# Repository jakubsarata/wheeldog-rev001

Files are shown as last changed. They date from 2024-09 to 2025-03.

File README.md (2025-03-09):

# Structurally Configurable Mobile Robot - Wheeldog_rev001
<p align="center">
  <table>
    <tr>
      <td></td>
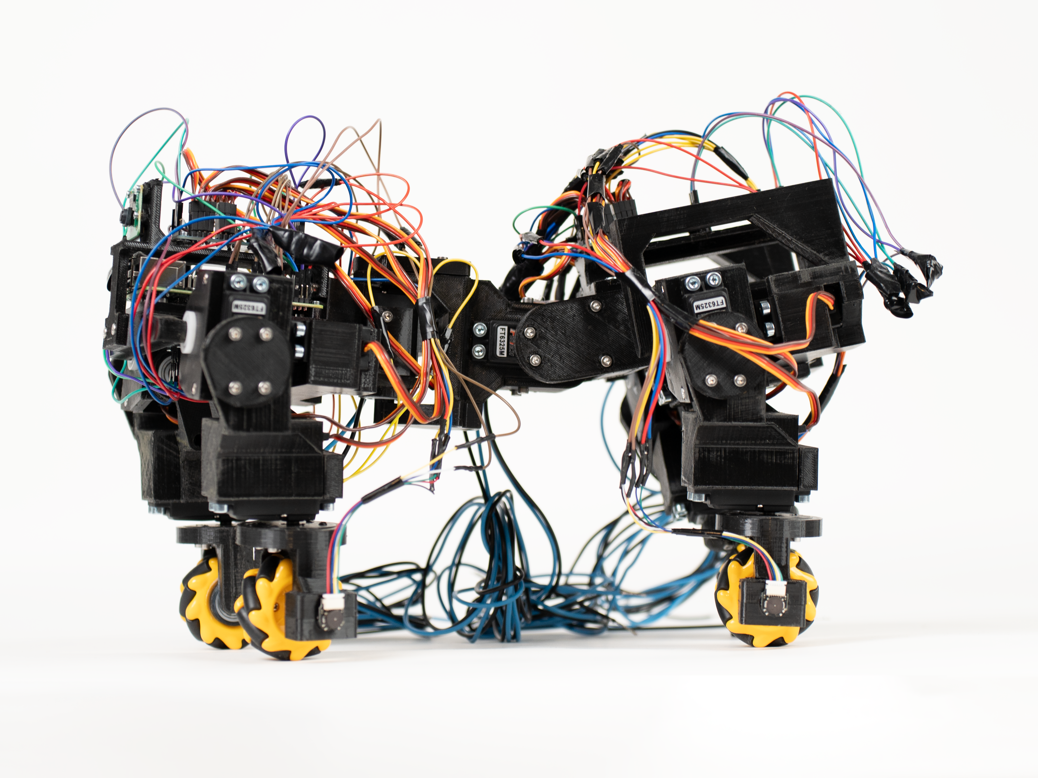
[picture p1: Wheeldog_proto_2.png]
      <td></td>
    </tr>
  </table>
</p>

## Overview
This project presents an open-source **structurally configurable mobile robot**, which combines the benefits of wheeled and legged locomotion. The robot is inspired by designs such as ANYmal, but with enhanced flexibility and mobility due to additional degrees of freedom and omnidirectional wheels.

Originally developed as part of a master's thesis at the **AGH University of Science and Technology**, this project is now available to the open-source community for further development and application.

## Features
- **Hybrid Locomotion**: Utilizes both wheels for speed and efficiency on smooth surfaces, and legs for traversing rough terrains and obstacles.
- **Adaptive Configuration**: The body features three degrees of freedom, allowing for movement akin to natural creatures like lizards.
- **Omnidirectional Wheels**: Enables maneuverability in tight spaces and precise movement control.
- **Simulation and Real-World Testing**: Verified through MATLAB simulations and physical prototyping.
- **Simulink Model**: A simulation model of the platform is available in MATLAB/Simulink R2022b using the Simscape Multibody toolbox.
- **Expandable and Modular**: Designed with 3D printing and modular assembly in mind, allowing for modifications and improvements.

## System Components
### Hardware
- **Actuators**: 15 Feetech FT6325M servomotors
- **Motors**: 4 Pololu 2373 DC motors
- **Main Controller**: Raspberry Pi 4B
- **Motor Drivers**: PCA9685 for servos, M2T256 for DC motors
- **Sensors**:
  - Adafruit 4754 IMU for motion tracking
  - Pololu 4761 encoders for wheel speed measurement
  - Raspberry Pi Camera HD v2 for future vision applications
- **Power Supply**: Laboratory power supply (for prototyping phase)
- **Chassis**: 3D-printed components

### Software
- **Programming Language**: Python & C++
- **Communication Protocols**: I2C for sensor and actuator control

## Getting Started
### Hardware Setup
1. **Assemble the chassis**: 3D print and attach all components as per the provided CAD files.
2. **Connect actuators and sensors**: Follow the wiring diagram.
3. **Power the system**: Use a stable power source for testing.

### Software Setup
To start using the robot, follow the steps outlined in the master’s thesis and the official guides provided by the manufacturers of the respective controllers and sensors. These documents include detailed instructions on setup, wiring, and configuration.

## Contribution
Contributions are welcome, but to ensure proper coordination, all changes must be reviewed before being merged. If you wish to improve or extend functionality:
1.**Fork the repository**
2.**Implement changes or bug fixes**
3.**Submit a pull request for review**

For major changes, please open an issue first to discuss your ideas. No changes will be merged without prior review and approval.

## License
This project is licensed under the **MIT License**, allowing for open collaboration and modifications.

## Acknowledgments
This project was initially developed as a **Master’s Thesis** at AGH University of Science and Technology.

## Contact
For inquiries, contributions, or discussions, feel free to reach out via GitHub Issues or email at **jakub.sarata@gmail.com**.

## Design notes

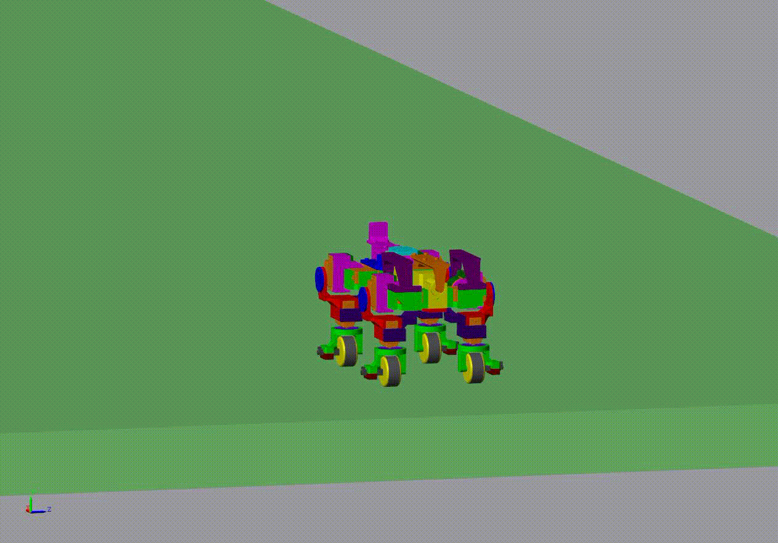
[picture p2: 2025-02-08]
Records/Crab_gait.gif

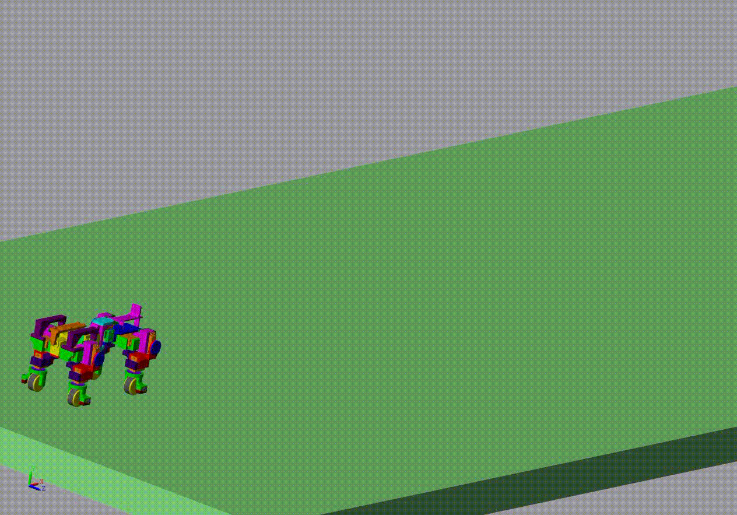
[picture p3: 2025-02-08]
Records/Crawling.gif

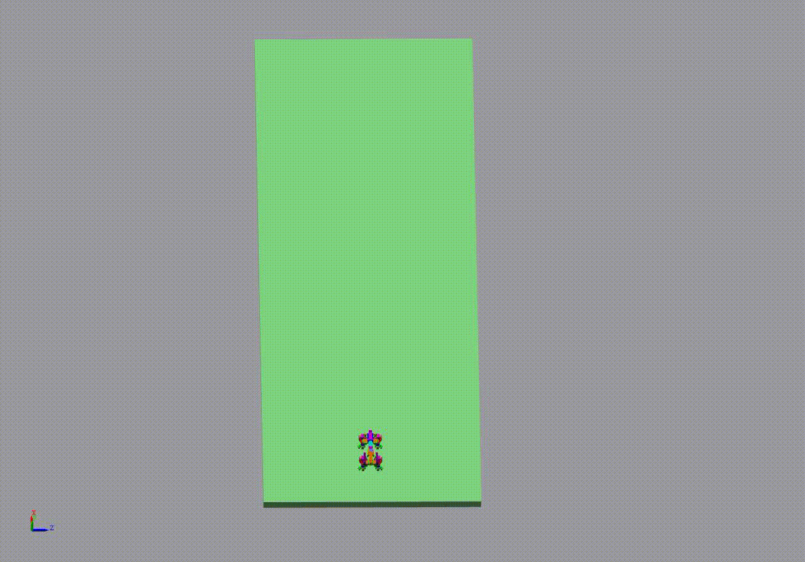
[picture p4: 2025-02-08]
Records/Slalom.gif

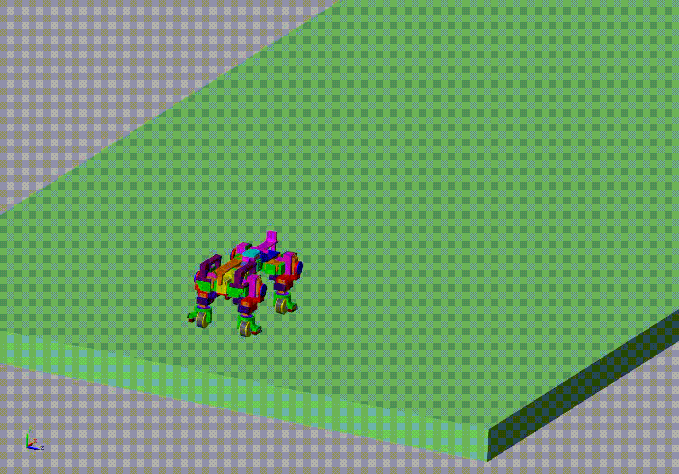
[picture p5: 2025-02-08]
Records/Lizard_gait.gif

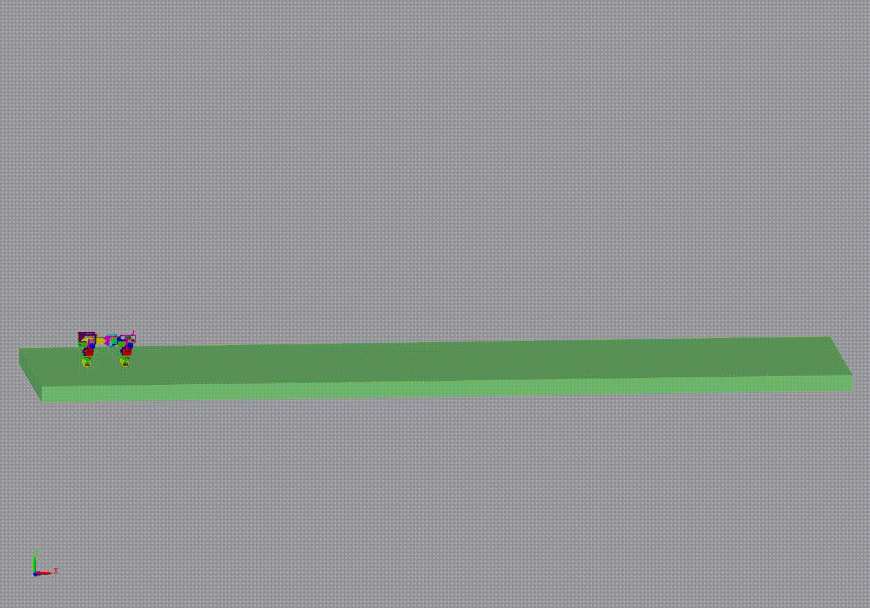
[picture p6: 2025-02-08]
Records/Driving_with_active_suspension.gif

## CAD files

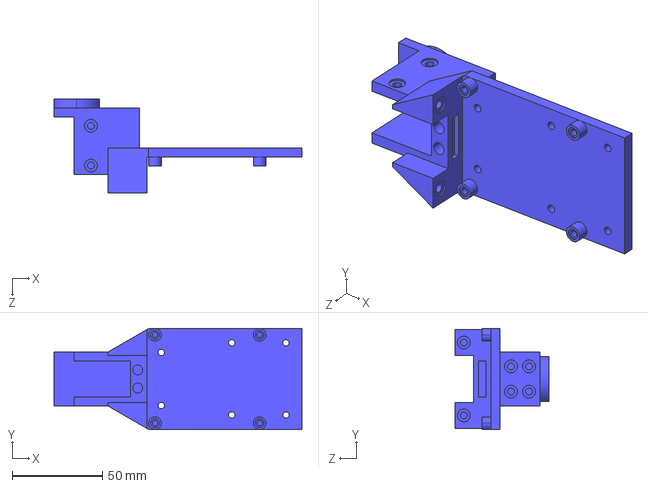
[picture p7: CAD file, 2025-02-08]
Project/Base/009_001_Underside_front.STEP
137.5 x 56.0 x 52.3 mm

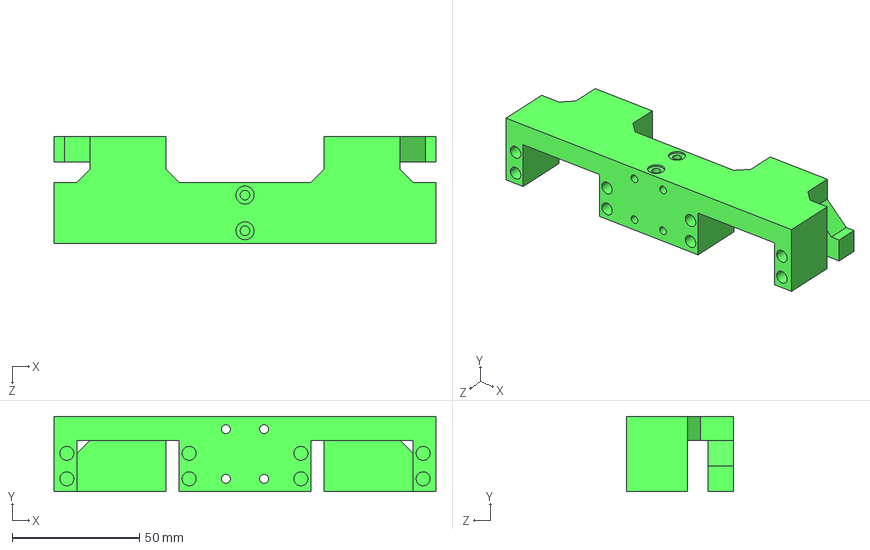
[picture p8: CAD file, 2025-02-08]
Project/Leg/010_017_Left_right_servo_mount_back.STEP
150.0 x 29.5 x 42.0 mm

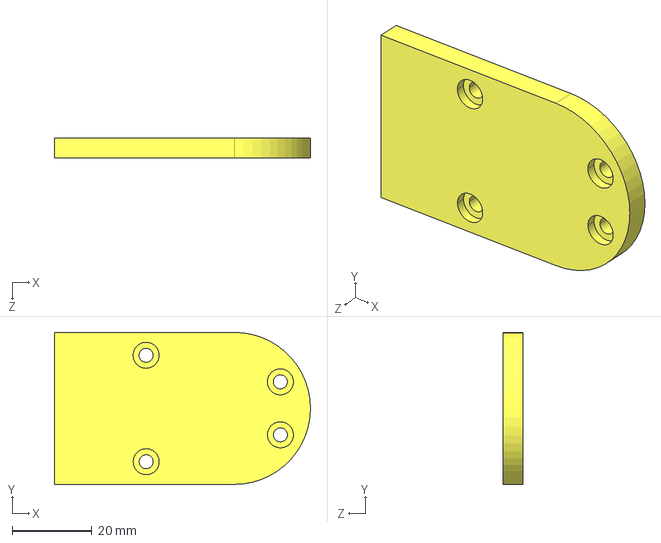
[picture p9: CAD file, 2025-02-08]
Project/Base/009_006_Up_down_connector_lock.STEP
64.0 x 38.0 x 5.00 mm

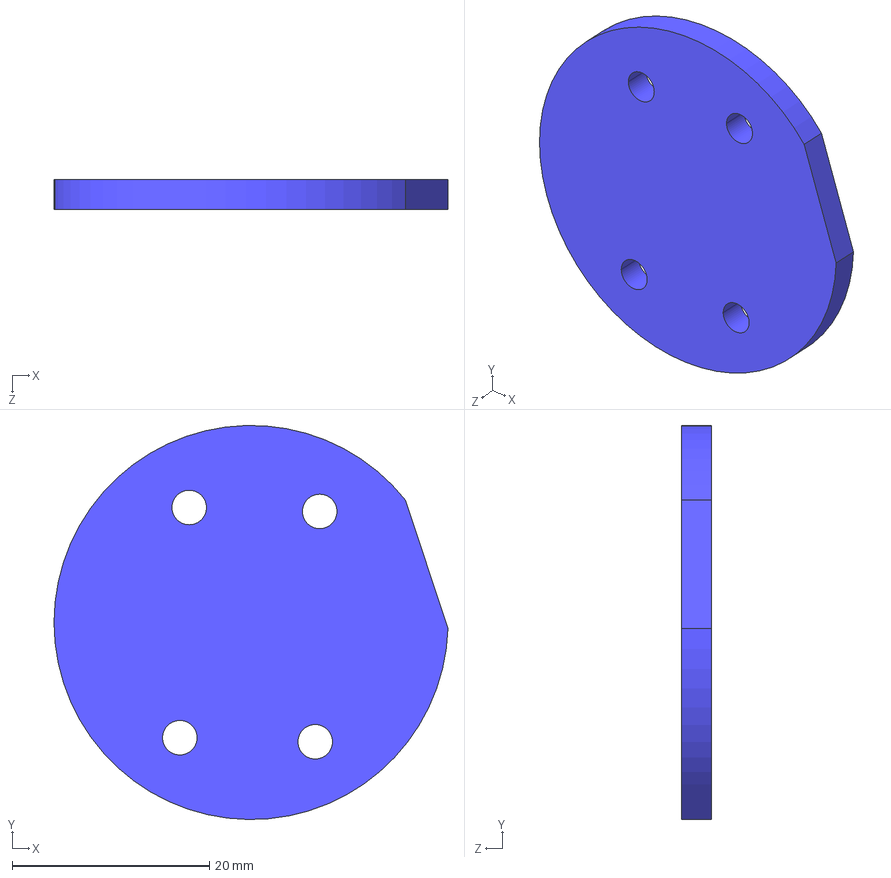
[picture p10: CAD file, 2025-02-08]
Project/Leg/010_009_Front_back_servo_lock_1.STEP
40.0 x 40.0 x 3.00 mm

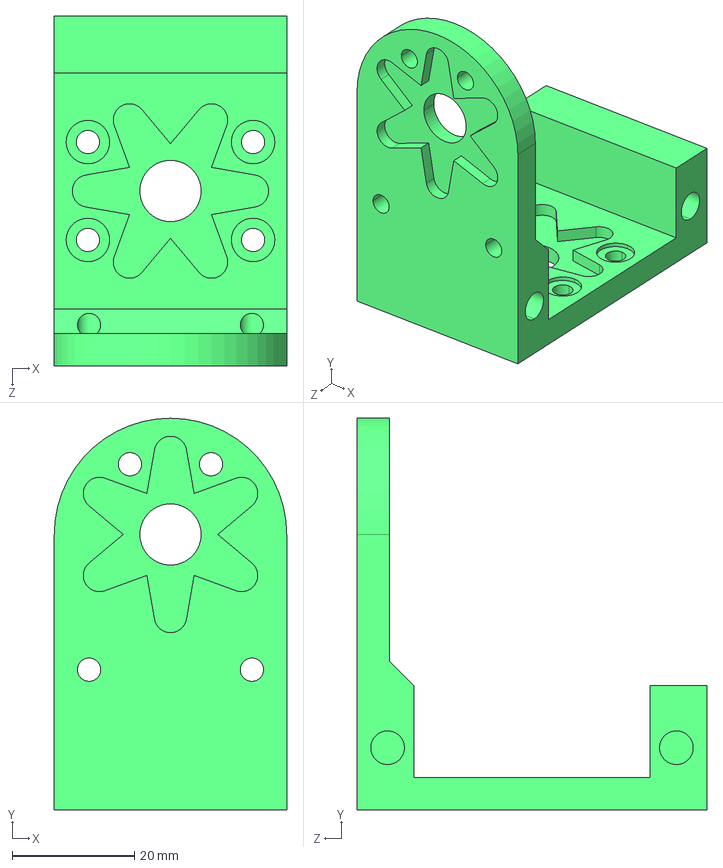
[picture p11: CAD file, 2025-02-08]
Project/Base/009_005_Up_down_connector.STEP
38.0 x 64.0 x 57.2 mm

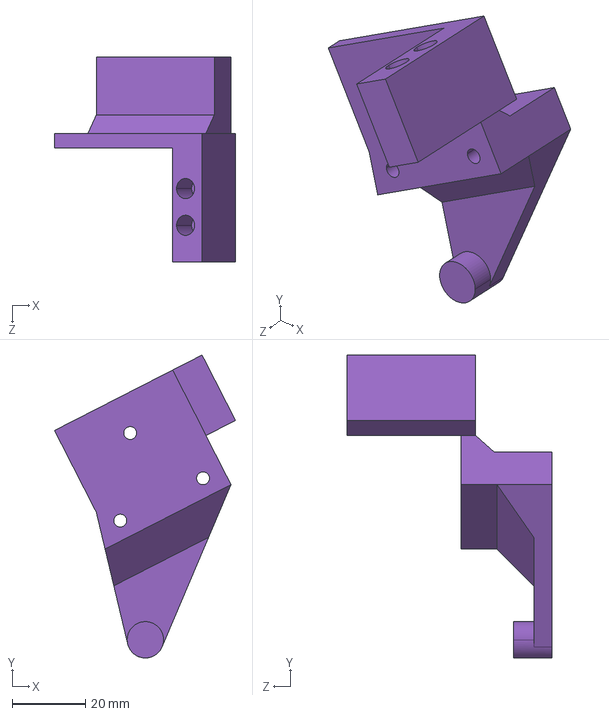
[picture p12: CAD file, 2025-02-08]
Project/Leg/010_013_Front_back_bearing_lock_2.STEP
49.3 x 82.5 x 55.9 mm

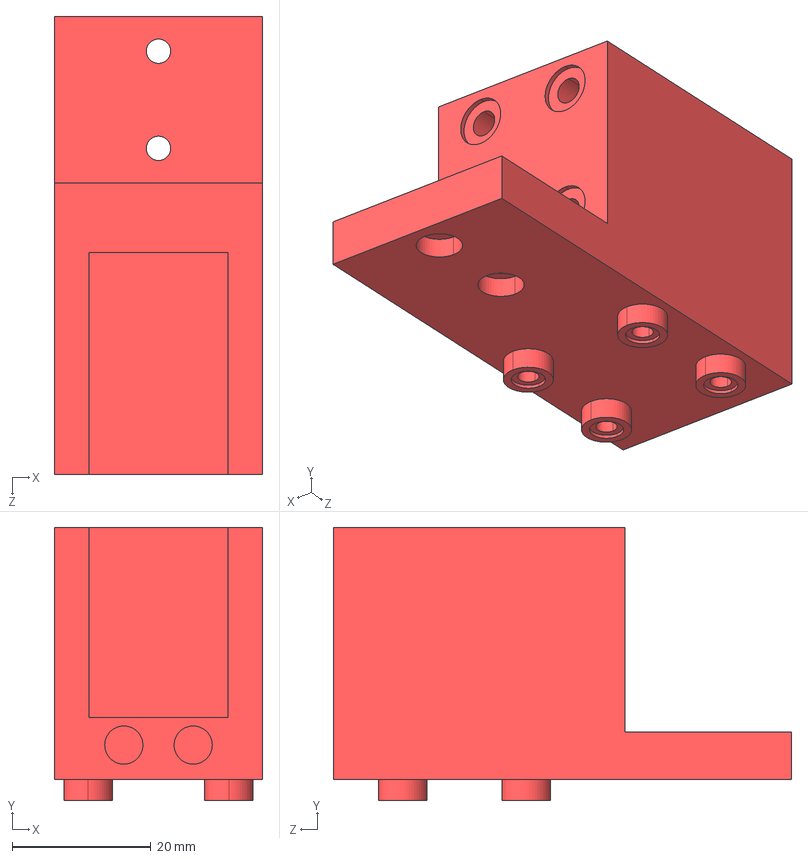
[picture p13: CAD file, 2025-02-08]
Project/Base/009_009_Spin_servo_mount_1.STEP
30.0 x 39.4 x 66.0 mm

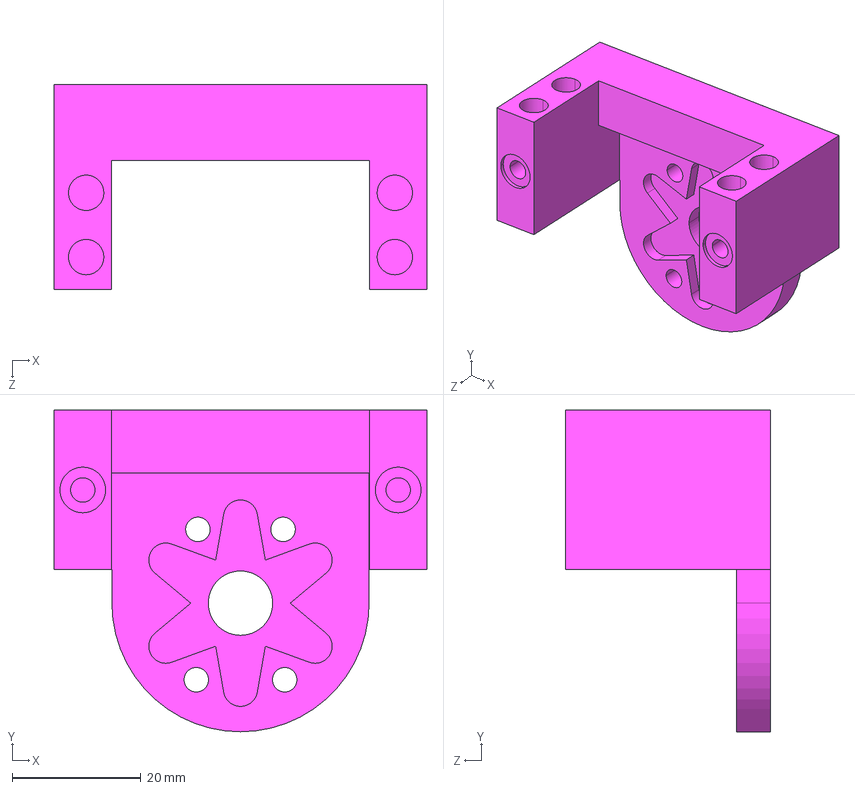
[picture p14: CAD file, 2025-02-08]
Project/Leg/010_006_Front_back_servo_mount_2.STEP
58.0 x 50.0 x 31.9 mm

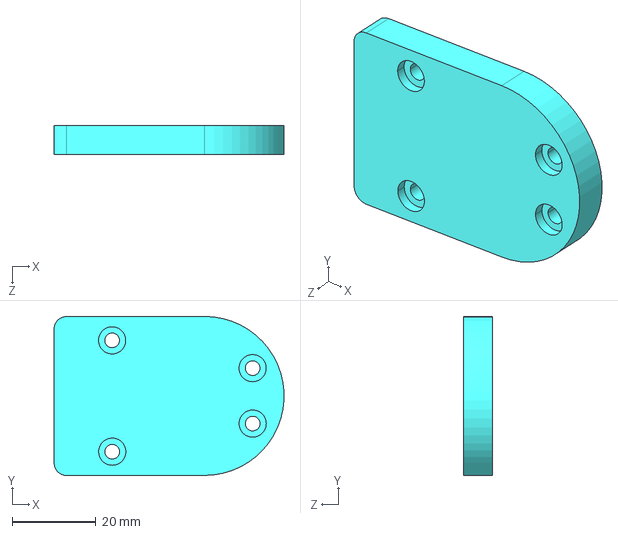
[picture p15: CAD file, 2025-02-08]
Project/Base/009_004_Left_right_connector_lock.STEP
55.0 x 38.0 x 7.00 mm

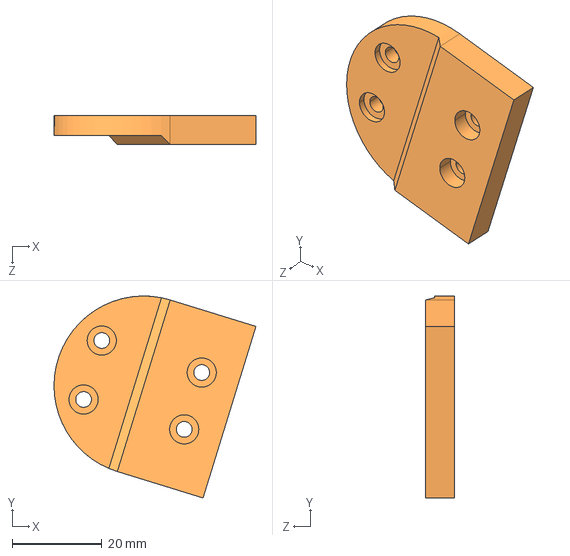
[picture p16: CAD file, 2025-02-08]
Project/Leg/010_003_Left_right_servo_lock.STEP
45.0 x 45.0 x 6.50 mm

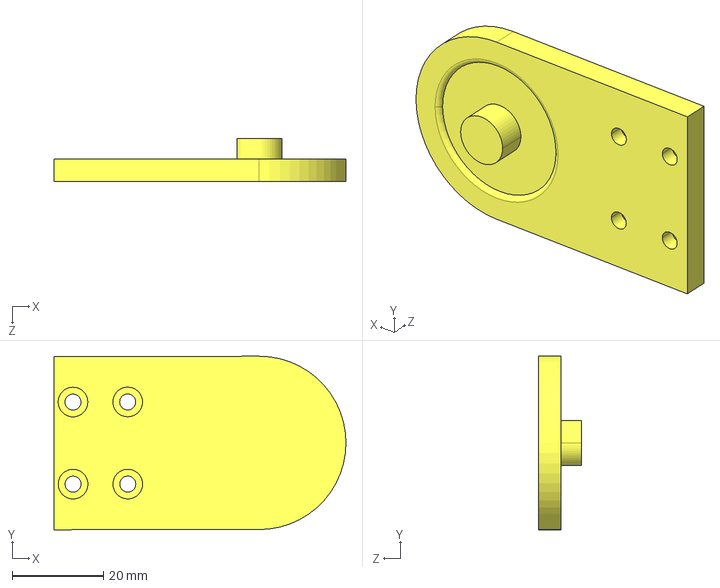
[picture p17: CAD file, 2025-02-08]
Project/Base/009_008_Up_down_bearing_grip.STEP
64.0 x 38.0 x 9.50 mm

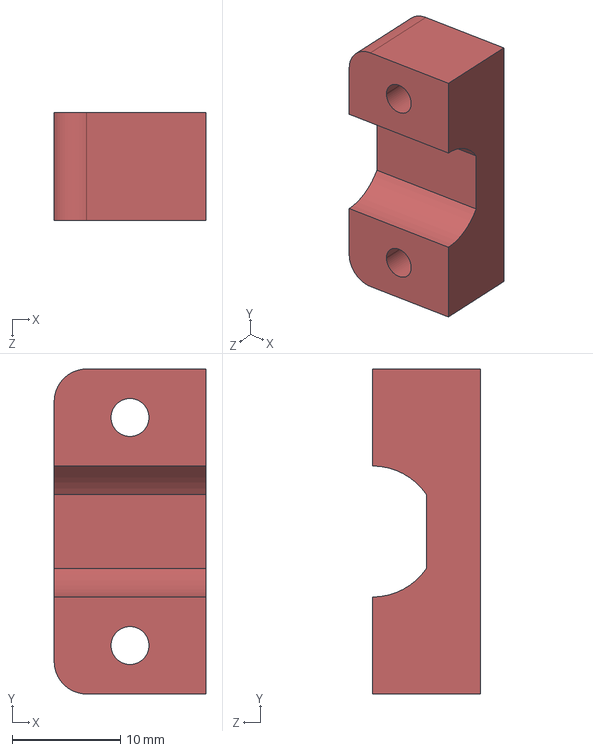
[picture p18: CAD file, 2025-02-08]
Project/Leg/010_016_Motor_lock.STEP
14.0 x 30.0 x 10.0 mm

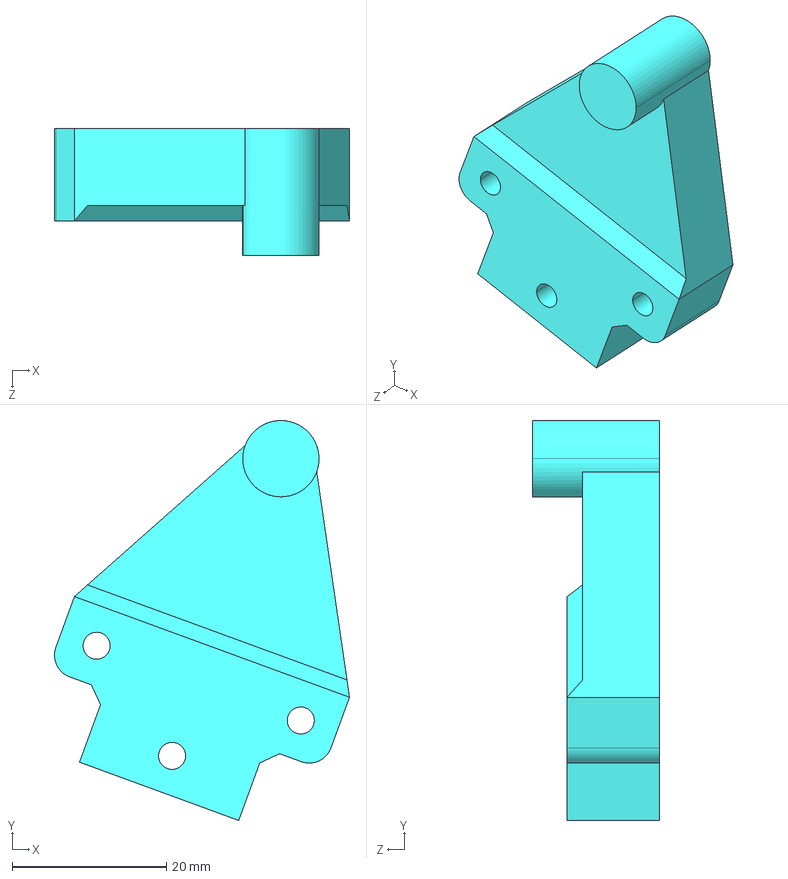
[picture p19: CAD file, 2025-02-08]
Project/Base/009_003_Left_right_connector_bearing_grip.STEP
38.3 x 51.9 x 16.5 mm

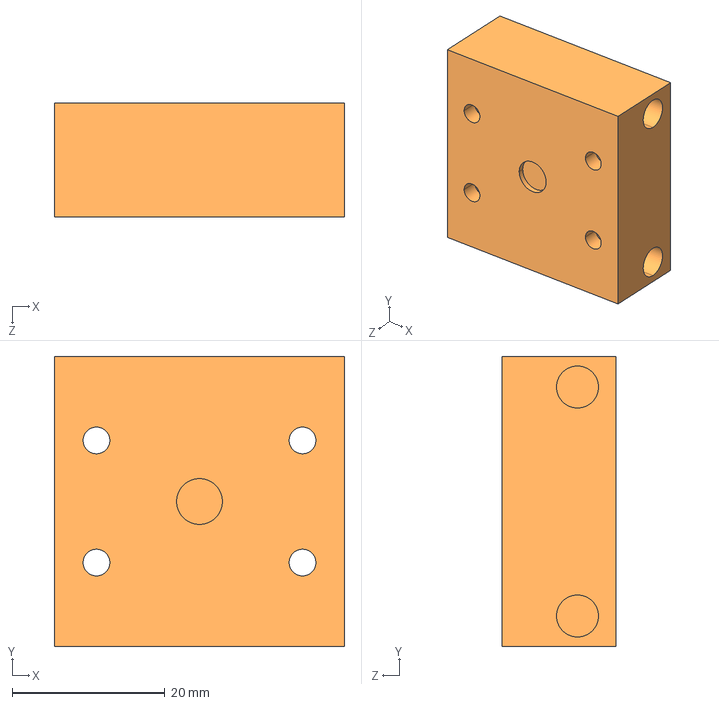
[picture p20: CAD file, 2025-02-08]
Project/Base/009_007_Spin_lock.STEP
38.0 x 38.0 x 15.0 mm

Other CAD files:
Project/Leg/010_012_Front_back_servo_lock_2.STEP
Project/Leg/010_014_Wheel_mount.STEP
Project/Base/009_012_Left_right_connector_servo_mount.STEP
Project/Leg/010_004_Bearing_mount_1.STEP
Project/Base/009_002_Left_right_connector.STEP
Project/Base/009_010_Spin_servo_mount_2.STEP
Project/Base/009_011_Underside_front_servo_mount.STEP
Project/Base/009_013_Spin_bearing_lock.STEP
Project/Base/011_006_Washer.STEP
Project/Leg/010_001_Left_right_servo_mount_front.STEP
Project/Leg/010_002_Front_back_servo_mount_1.STEP
Project/Leg/010_005_Bearing_mount_2.STEP
Project/Leg/010_007_Left_right_bearing_lock.STEP
Project/Leg/010_008_Spin_servo_mount_1.STEP
Project/Leg/010_010_Front_back_bearing_lock_1.STEP
Project/Leg/010_011_Spin_servo_mount_2.STEP
Project/Leg/010_015_Wheel_mount.STEP
Project/Leg/010_018_Camera_mount.STEP
Project/Leg/010_019_Left_right_bearing_mount_back_1.STEP
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

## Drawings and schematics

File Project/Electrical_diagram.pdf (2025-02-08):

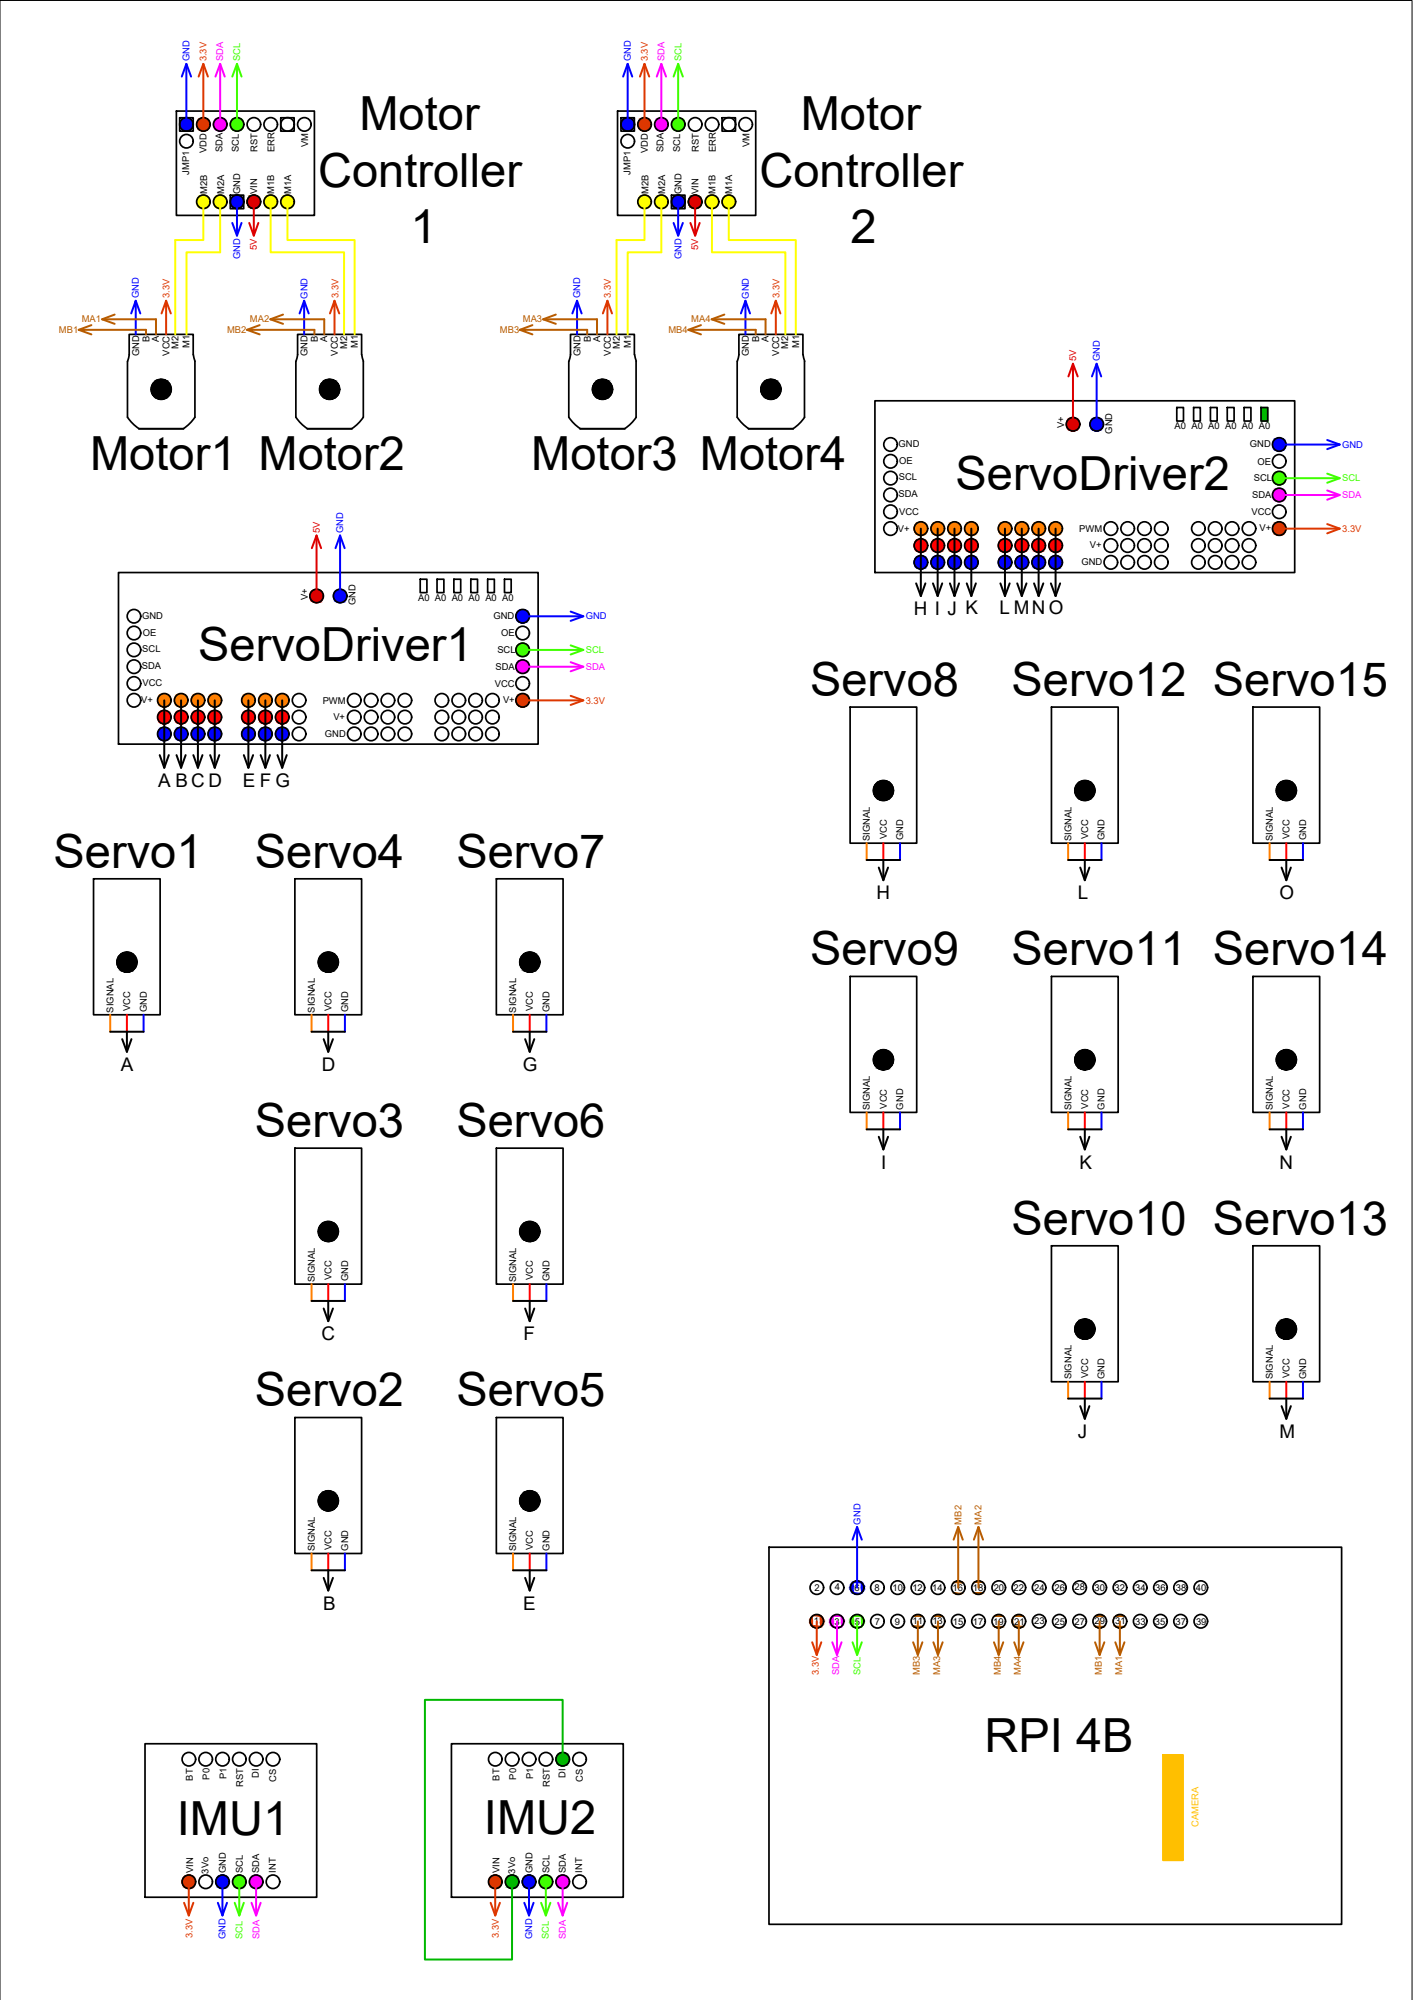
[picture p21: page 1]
RPI 4B; GND OE; SCL VCC; SDA GNDOE; PWM; V+ V+ GND V+; GND BT; RSTDI; CS VIN 3Vo; GND; SCL; SDA; INT; IMU1; GND SCL; Servo1 SIGNAL; VCC GND; Servo4 SIGNAL; Servo7 SIGNAL; Servo3 SIGNAL; Servo6 SIGNAL; Servo2 SIGNAL; Servo5 SIGNAL; Servo8 SIGNAL; Servo12 SIGNAL; Servo15 SIGNAL; Servo11 SIGNAL; Servo14 SIGNAL; Servo10 SIGNAL; Servo13 SIGNAL; Servo9 SIGNAL; L M O M2 M1 VCCB A GND; Motor1 GND; M2 M1 VCCB; A GND; Motor2 M2B; M2A GND VIN M1B; VM VDD SDA; RST; ERR JMP1; SCL GND GND; GND 5V; SCL SDA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

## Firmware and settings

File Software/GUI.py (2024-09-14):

import time
from adafruit_servokit import ServoKit
import motoron
import tkinter as tk
from tkinter import messagebox
import cv2

#inicjalizacja klas serwomechanizmów
kit = ServoKit(channels=16, address=0x40)
kit1 = ServoKit(channels=16, address=0x41)

#inicjalizacja silników
mc1 = motoron.MotoronI2C(address=16)
mc2 = motoron.MotoronI2C(address=17)

def setup_motoron(mc):
  mc.reinitialize()
  mc.disable_crc()
  mc.clear_reset_flag()

setup_motoron(mc1)
setup_motoron(mc2)

mc1.set_max_acceleration(1, 80)
mc1.set_max_deceleration(1, 300)

mc1.set_max_acceleration(2, 80)
mc1.set_max_deceleration(2, 300)


mc2.set_max_acceleration(1, 80)
mc2.set_max_deceleration(1, 300)

mc2.set_max_acceleration(2, 80)
mc2.set_max_deceleration(2, 300)

#Ustawienie początkowych wartości serwomechanizmów
Base_Left_Right = 100 #tułów prawo lewo
Base_Up_Down = 90 #tułów góra dół
Base_Spin = 90 #tułów skręcanie

RF_Abduction = 98 #prawy przód odwodzenie
RF_Front_back = 85 #prawy przód przód-tył
RF_Spin = 20 #prawy przód obrót kołem

LF_Abduction = 100 #lewy przód odwodzenie
LF_Front_back = 130 #lewy przód przód-tył
LF_Spin = 100 #lewy przód obrót kołem

LB_Abduction = 100 #lewy tył odwodzenie
LB_Front_back = 110 #lewy tył przód-tył
LB_Spin = 100 #lewy tył obrót kołem

RB_Abduction = 85 #prawy przód odwodzenie
RB_Front_back = 90 #prawy przód przód-tył
RB_Spin = 20 #prawy przód obrót kołem

# Obsługa tułowia
def Base_Left():
    global Base_Left_Right
    Base_Left_Right = Base_Left_Right - 1
    kit.servo[0].angle = Base_Left_Right 
    return Base_Left_Right

def Base_Right():
    global Base_Left_Right
    Base_Left_Right = Base_Left_Right + 1
    kit.servo[0].angle = Base_Left_Right
    return Base_Left_Right

def Base_Up():
    global Base_Up_Down
    Base_Up_Down = Base_Up_Down - 1
    kit1.servo[0].angle = Base_Up_Down 
    return Base_Up_Down

def Base_Down():
    global Base_Up_Down
    Base_Up_Down = Base_Up_Down + 1
    kit1.servo[0].angle = Base_Up_Down
    return Base_Up_Down

def Base_Spin_Clockwise():
    global Base_Spin
    Base_Spin = Base_Spin - 1
    kit1.servo[1].angle = Base_Spin
    return Base_Spin

def Base_Spin_Counterclockwise():
    global Base_Spin
    Base_Spin = Base_Spin + 1
    kit1.servo[1].angle = Base_Spin
    return Base_Spin        
# Obsługa tułowia

# Obsługa noga prawy przód
def Leg_RF_Abduction():
    global RF_Abduction
    RF_Abduction = RF_Abduction - 1
    kit.servo[6].angle = RF_Abduction
    return RF_Abduction 

def Leg_RF_Adduction():
    global RF_Abduction
    RF_Abduction = RF_Abduction + 1
    kit.servo[6].angle = RF_Abduction
    return RF_Abduction 
 
def Leg_RF_Front():
    global RF_Front_back
    RF_Front_back = RF_Front_back + 1
    kit.servo[5].angle = RF_Front_back
    return RF_Front_back


def Leg_RF_Back():
    global RF_Front_back
    RF_Front_back = RF_Front_back - 1
    kit.servo[5].angle = RF_Front_back
    return RF_Front_back


def Leg_RF_Clockwise():
    global RF_Spin
    RF_Spin = RF_Spin + 1
    kit.servo[4].angle = RF_Spin
    return RF_Spin

def Leg_RF_Counterclockwise():
    global RF_Spin
    RF_Spin = RF_Spin - 1
    kit.servo[4].angle = RF_Spin
    return RF_Spin
# Obsługa noga prawy przód

# Obsługa noga lewy przód
def Leg_LF_Abduction():
    global LF_Abduction
    LF_Abduction = LF_Abduction + 1
    kit.servo[3].angle = LF_Abduction
    return LF_Abduction 

def Leg_LF_Adduction():
    global LF_Abduction
    LF_Abduction = LF_Abduction - 1
    kit.servo[3].angle = LF_Abduction
    return LF_Abduction 
 
def Leg_LF_Front():
    global LF_Front_back
    LF_Front_back = LF_Front_back - 1
    kit.servo[2].angle = LF_Front_back
    return LF_Front_back


def Leg_LF_Back():
    global LF_Front_back
    LF_Front_back = LF_Front_back + 1
    kit.servo[2].angle = LF_Front_back
    return LF_Front_back


def Leg_LF_Clockwise():
    global LF_Spin
    LF_Spin = LF_Spin + 1
    kit.servo[1].angle = LF_Spin
    return LF_Spin

def Leg_LF_Counterclockwise():
    global LF_Spin
    LF_Spin = LF_Spin - 1
    kit.servo[1].angle = LF_Spin
    return LF_Spin
# Obsługa noga lewy przód

# Obsługa noga lewy tył
def Leg_LB_Abduction():
    global LB_Abduction
    LB_Abduction = LB_Abduction + 1
    kit1.servo[4].angle = LB_Abduction
    return LB_Abduction 

def Leg_LB_Adduction():
    global LB_Abduction
    LB_Abduction = LB_Abduction - 1
    kit1.servo[4].angle = LB_Abduction
    return LB_Abduction 
 
def Leg_LB_Front():
    global LB_Front_back
    LB_Front_back = LB_Front_back - 1
    kit1.servo[3].angle = LB_Front_back
    return LB_Front_back


def Leg_LB_Back():
    global LB_Front_back
    LB_Front_back = LB_Front_back + 1
    kit1.servo[3].angle = LB_Front_back
    return LB_Front_back

def Leg_LB_Clockwise():
    global LB_Spin
    LB_Spin = LB_Spin + 1
    kit1.servo[2].angle = LB_Spin
    return LB_Spin

def Leg_LB_Counterclockwise():
    global LB_Spin
    LB_Spin = LB_Spin - 1
    kit1.servo[2].angle = LB_Spin
    return LB_Spin
# Obsługa noga lewy tył

# Obsługa noga prawy tył
def Leg_RB_Abduction():
    global RB_Abduction
    RB_Abduction = RB_Abduction - 1
    kit1.servo[7].angle = RB_Abduction
    return RB_Abduction 

def Leg_RB_Adduction():
    global RB_Abduction
    RB_Abduction = RB_Abduction + 1
    kit1.servo[7].angle = RB_Abduction
    return RB_Abduction 
 
def Leg_RB_Front():
    global RB_Front_back
    RB_Front_back = RB_Front_back + 1
    kit1.servo[6].angle = RB_Front_back
    return RB_Front_back


def Leg_RB_Back():
    global RB_Front_back
    RB_Front_back = RB_Front_back - 1
    kit1.servo[6].angle = RB_Front_back
    return RB_Front_back


def Leg_RB_Clockwise():
    global RB_Spin
    RB_Spin = RB_Spin + 1
    kit1.servo[5].angle = RB_Spin
    return RB_Spin

def Leg_RB_Counterclockwise():
    global RB_Spin
    RB_Spin = RB_Spin - 1
    kit1.servo[5].angle = RB_Spin
    return RB_Spin
# Obsługa noga prawy tył

# Obsługa koła
def Forward():
    mc1.set_speed(1, 800)
    mc1.set_speed(2, -800)
    mc2.set_speed(1, 800)
    mc2.set_speed(2, -800)
    time.sleep(0.5)

def Reverse():
    mc1.set_speed(1, -800)
    mc1.set_speed(2, 800)
    mc2.set_speed(1, -800)
    mc2.set_speed(2, 800)
    time.sleep(0.5)

def Right():
    mc1.set_speed(1, 800)
    mc1.set_speed(2, 800)
    mc2.set_speed(1, 800)
    mc2.set_speed(2, 800)
    time.sleep(0.5)

def Left():
    mc1.set_speed(1, -800)
    mc1.set_speed(2, -800)
    mc2.set_speed(1, -800)
    mc2.set_speed(2, -800)
    time.sleep(0.5)
# Obsługa koła

# Kamera
def Camera():
    cap = cv2.VideoCapture('/dev/video0', cv2.CAP_V4L)
    cap.set(cv2.CAP_PROP_FRAME_WIDTH, 2560)
    cap.set(cv2.CAP_PROP_FRAME_HEIGHT, 1440)
    ret, frame = cap.read()
    cv2.imwrite('image.jpg', frame)
    cap.release()
# Kamera

def main():

    global root
    root = tk.Tk()
    root.title("Wheeldog")

    # Obsługa tułowia przyciski
    labelframe1 = tk.LabelFrame(root, text="Base", padx=10, pady=10) 
    labelframe1.grid(row=0, column=0, padx=20, pady=20)

    frame = tk.Frame(root)
    frame.grid(row=0, column=0, padx=20, pady=20)

    button1 = tk.Button(labelframe1, text="Base Left", command=Base_Left)
    button1.grid(row=0, column=0, padx=10)

    button2 = tk.Button(labelframe1, text="Base Right", command=Base_Right)
    button2.grid(row=0, column=1, padx=10)

    button3 = tk.Button(labelframe1, text="Base Up", command=Base_Up)
    button3.grid(row=1, column=0, pady=10)

    button4 = tk.Button(labelframe1, text="Base Down", command=Base_Down)
    button4.grid(row=1, column=1, pady=10)

    button5 = tk.Button(labelframe1, text="Base Clockwise", command=Base_Spin_Clockwise)
    button5.grid(row=2, column=0, columnspan=2, pady=10)

    button6 = tk.Button(labelframe1, text="Base Counterclockwise", command=Base_Spin_Counterclockwise)
    button6.grid(row=3, column=0, columnspan=2, pady=10)
    # Obsługa tułowia przyciski

    #Obsługa noga prawy przód
    labelframe2 = tk.LabelFrame(root, text="Leg Right Front", padx=10, pady=10) 
    labelframe2.grid(row=0, column=5, padx=20, pady=20)

    button7 = tk.Button(labelframe2, text="RF Abduction", command=Leg_RF_Abduction)
    button7.grid(row=0, column=5, padx=10) 

    button8 = tk.Button(labelframe2, text="RF Adduction", command=Leg_RF_Adduction)
    button8.grid(row=0, column=6, padx=10)

    button9 = tk.Button(labelframe2, text="RF Front", command=Leg_RF_Front)
    button9.grid(row=1, column=5, pady=10) 

    button10 = tk.Button(labelframe2, text="RF Back", command=Leg_RF_Back)
    button10.grid(row=1, column=6, pady=10)  


    button11 = tk.Button(labelframe2, text="RF Clockwise", command=Leg_RF_Clockwise)
    button11.grid(row=2, column=5, pady=10) 

    button12 = tk.Button(labelframe2, text="RF Counterclockwise", command=Leg_RF_Counterclockwise)
    button12.grid(row=2, column=6, pady=10)
    #Obsługa noga prawy przód

    #Obsługa noga lewy przód
    labelframe3 = tk.LabelFrame(root, text="Leg Left Front", padx=10, pady=10) 
    labelframe3.grid(row=0, column=3, padx=20, pady=20)

    button13 = tk.Button(labelframe3, text="LF Abduction", command=Leg_LF_Abduction)
    button13.grid(row=0, column=3, padx=10) 

    button14 = tk.Button(labelframe3, text="LF Adduction", command=Leg_LF_Adduction)
    button14.grid(row=0, column=4, padx=10)

    button14 = tk.Button(labelframe3, text="LF Front", command=Leg_LF_Front)
    button14.grid(row=1, column=3, pady=10) 

    button15 = tk.Button(labelframe3, text="LF Back", command=Leg_LF_Back)
    button15.grid(row=1, column=4, pady=10)  


    button16 = tk.Button(labelframe3, text="LF Clockwise", command=Leg_LF_Clockwise)
    button16.grid(row=2, column=3, pady=10) 

    button17 = tk.Button(labelframe3, text="LF Counterclockwise", command=Leg_LF_Counterclockwise)
    button17.grid(row=2, column=4, pady=10)
    #Obsługa noga lewy przód

    #Obsługa noga lewy tył
    labelframe4 = tk.LabelFrame(root, text="Leg Left Back", padx=10, pady=10) 
    labelframe4.grid(row=4, column=3, padx=20, pady=20)

    button18 = tk.Button(labelframe4, text="LB Abduction", command=Leg_LB_Abduction)
    button18.grid(row=4, column=3, padx=10) 

    button19 = tk.Button(labelframe4, text="LB Adduction", command=Leg_LB_Adduction)
    button19.grid(row=4, column=4, padx=10)

    button20 = tk.Button(labelframe4, text="LB Front", command=Leg_LB_Front)
    button20.grid(row=5, column=3, pady=10) 

    button21 = tk.Button(labelframe4, text="LB Back", command=Leg_LB_Back)
    button21.grid(row=5, column=4, pady=10)  


    button22 = tk.Button(labelframe4, text="LB Clockwise", command=Leg_LB_Clockwise)
    button22.grid(row=6, column=3, pady=10) 

    button23 = tk.Button(labelframe4, text="LB Counterclockwise", command=Leg_LB_Counterclockwise)
    button23.grid(row=6, column=4, pady=10)
    #Obsługa noga lewy tył

    #Obsługa noga prawy tył
    labelframe5 = tk.LabelFrame(root, text="Leg Right Back", padx=10, pady=10) 
    labelframe5.grid(row=4, column=5, padx=20, pady=20)

    button24 = tk.Button(labelframe5, text="RB Abduction", command=Leg_RB_Abduction)
    button24.grid(row=4, column=5, padx=10) 

    button25 = tk.Button(labelframe5, text="RB Adduction", command=Leg_RB_Adduction)
    button25.grid(row=4, column=6, padx=10)

    button26 = tk.Button(labelframe5, text="RB Front", command=Leg_RB_Front)
    button26.grid(row=5, column=5, pady=10) 

    button27 = tk.Button(labelframe5, text="RB Back", command=Leg_RB_Back)
    button27.grid(row=5, column=6, pady=10)  


    button28 = tk.Button(labelframe5, text="RB Clockwise", command=Leg_RB_Clockwise)
    button28.grid(row=6, column=5, pady=10) 

    button29 = tk.Button(labelframe5, text="RB Counterclockwise", command=Leg_RB_Counterclockwise)
    button29.grid(row=6, column=6, pady=10)
    #Obsługa noga prawy tył

    #Obsługa koła
    labelframe6 = tk.LabelFrame(root, text="Driving", padx=10, pady=10) 
    labelframe6.grid(row=4, column=0, padx=20, pady=20)

    button30 = tk.Button(labelframe6, text="Forward", command=Forward)
    button30.grid(row=4, column=0, columnspan=2, padx=10) 

    button31 = tk.Button(labelframe6, text="Right", command=Right)
    button31.grid(row=5, column=1, padx=10)

    button32 = tk.Button(labelframe6, text="Left", command=Left)
    button32.grid(row=5, column=0, pady=10)

    button33 = tk.Button(labelframe6, text="Reverse", command=Reverse)
    button33.grid(row=6, column=0, columnspan=2, pady=10) 
    #Obsługa koła

    #Obsługa kamery
    labelframe7 = tk.LabelFrame(root, text="Camera", padx=10, pady=10) 
    labelframe7.grid(row=7, column=0, padx=20, pady=20)

    button34 = tk.Button(labelframe7, text="Take a photo", command=Camera)
    button34.grid(row=7, column=0, columnspan=2, padx=10) 

    #Obsługa kamery

    root.mainloop()


if __name__ == "__main__":
    main()
